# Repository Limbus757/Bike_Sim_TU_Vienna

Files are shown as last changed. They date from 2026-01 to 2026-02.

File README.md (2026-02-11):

# Bike_Sim_TU_Vienna
**Bachelor Thesis Project | TU Wien**

An immersive bicycle simulation environment developed at TU Wien, integrating Unity-based visualization with Arduino hardware for real-time interaction.

Project Overview

---
## Project Structure

| Folder / File | Description |
| :--- | :--- |
| **`Unity Project/`** | The core simulation built in Unity. Includes physics, environments, and UI. |
| **`Arduino Files/`** | Microcontroller firmware for sensor data acquisition and haptic feedback. |
| **`Data Analysis/`** | Scripts and tools for processing simulation logs and performance metrics. |
| **`Documents and 3D Prints/`** | CAD files, datasheets for the elctronics |
---

## Getting Started

### 1. Hardware Setup
* **Microcontroller:** [e.g., Arduino Nano/Uno]
* **Sensors:** [e.g., Potentiometers for steering, Hall effect for speed]
* Upload the code found in `/Arduino Files/` using the Arduino IDE.

### 2. Unity Simulation
* **Version:** [Insert Unity Version, e.g., 2022.3 LTS]
* Open the `Unity Project` folder in Unity Hub.
* Ensure the COM port in the simulation settings matches your Arduino port.

### 3. Data Analysis
* Post-processing scripts are located in `/Data Analysis/`.
* [Optional: Mention if Python or MATLAB is required].

---

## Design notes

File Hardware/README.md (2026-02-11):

# Bike Simulator: Arduino Control System

This repository contains the firmware and hardware documentation for the Bike Simulator project developed at TU Vienna. The system utilizes a dual-microcontroller architecture to bridge the gap between physical hardware (Tacx Trainer, sensors, and motors) and the Unity simulation environment.

---

## Hardware Architecture

The system is split into two primary controllers to ensure real-time performance and safety:

### 1. ESP32-S3: Telemetry Bridge & Sensor Hub
Located in the ESP32-S3_SerialSender folder, this controller acts as the central communication hub.
* **Dual-Core Execution**: Utilizes FreeRTOS to run BLE/Radio management on Core 1 and Serial/PC communication on Core 0 to prevent timing jitter.
* **BLE Connectivity**: Connects to a TACX-II trainer via the Fitness Machine Service (FTMS) using a specific MAC address.
* **Sensor Integration**: Reads analog brake force from front and rear brakes (mapped from 12-bit ADC to a 0-100 scale) and monitors a digital Lane Keep Assist (LKA) toggle.
* **Dynamic Resistance**: Maps total braking force (0-200% sum) to FTMS resistance units (0-1000) and sends it to the trainer.
* **Telemetry Streaming**: Streams 21-byte packed binary packets to the PC at 50Hz (20ms intervals) via Serial.

### 2. Arduino R4 WiFi: Actuator & Haptics Controller
Located in the Arduino-R4-Wifi_SerialReceiver folder, this controller translates Unity commands into physical movement.
* **Steering Control**: Drives a steering motor via a GPT Timer at 20kHz with 12-bit resolution.
* **Haptic Feedback**: Controls DRV2605 haptic drivers via PWM to provide tactile feedback.
* **Safety Watchdog**: Automatically sets motors to a safe state if the Unity application stops responding for more than 75ms.
* **High-Speed Serial**: Operates at a baud rate of 256,000 to ensure low-latency control.

---

## Communication Protocols
Both controllers use a structured binary packet format to ensure efficient data transfer with minimal overhead.

### Telemetry Packet (ESP32 -> PC)
| **Sync Header** | 0xAA 0xBB |
| **Payload** | 21 Bytes: Speed, Front/Rear Brake, Resistance, LKA Switch, Timing |
| **Tail** | 0xCC |

### Control Packet (PC -> Arduino R4)
| **Sync Header** | 0xAA 0xBB |
| **Payload** | 11 Bytes: Motor Enable, Direction, Steering PWM, Haptic PWM |
| **Tail** | 0xCC |

---

### LED Status Indicators (ESP32-S3)
The built-in RGB LED on the ESP32 provides immediate visual feedback on the system state:
* **Red**: Disconnected or initialization failure.
* **Yellow**: Searching for the Tacx Trainer MAC address.
* **Blue**: BLE radio link established (Service Discovery).
* **Purple**: FTMS Handshake in progress (Requesting Control).
* **Green**: Fully Synchronized & Control Active.

---

### Setup & Installation
1.  **Dependencies**:
    * **ESP32**: Requires the NimBLE-Arduino library.
    * **Arduino R4**: Requires Adafruit_DRV2605.h and the included pwm.h.
2.  **Configuration**:
    * In ESP32-S3_SerialSender.ino, verify the TARGET_MAC_ADDR matches your trainer.
3.  **Deployment**:
    * Upload the respective .ino files to their target boards using the Arduino IDE.

## Mechanical & Technical Documentation

In addition to the firmware, this repository includes integrated design and technical files located in the Documents and 3D Prints folder.

### 3D Design Files
* **Format**: All mechanical parts are provided as STEP files, ensuring compatibility with most CAD software (Fusion 360, SolidWorks, etc.).
* **Components**: Includes custom-designed mounts for attaching the sensors, microcontrollers, and the steering motor assembly to the bike frame.

### Technical Datasheets
* **Reference Material**: Includes datasheets for the core electronic components, such as the DRV2605 haptic drivers and motor controllers, to assist with wiring and electrical troubleshooting.

---

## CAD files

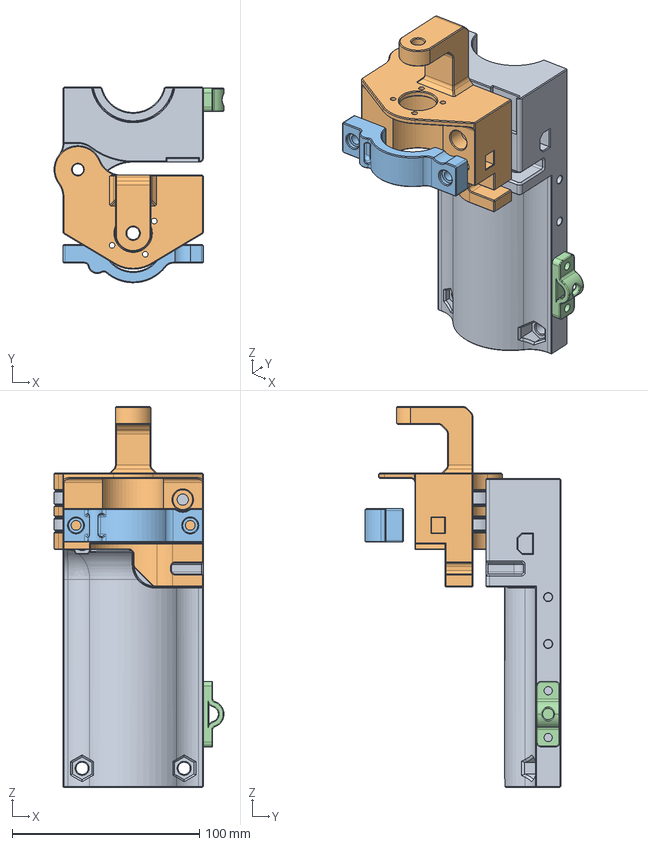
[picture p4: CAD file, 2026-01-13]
Hardware/Datasheets and 3D Prints/3D Print STEP files/Steering_Motor_Clamp_Assembly.step
90.7 x 104.5 x 203.5 mm
Frameclamp_Long
Motor_Mount
FrameClamps_Back
Strain_Relief_Clips

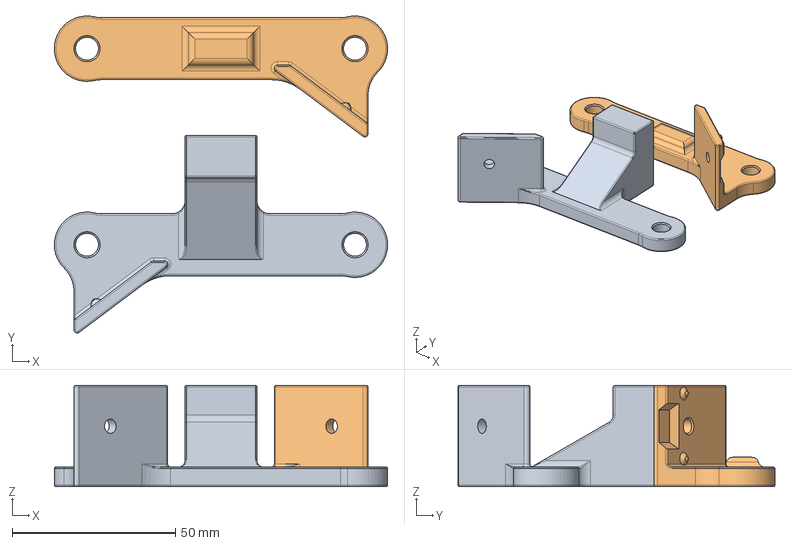
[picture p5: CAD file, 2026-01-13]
Hardware/Datasheets and 3D Prints/3D Print STEP files/Brake_Sensor_Mounts.step
102.0 x 97.0 x 31.0 mm

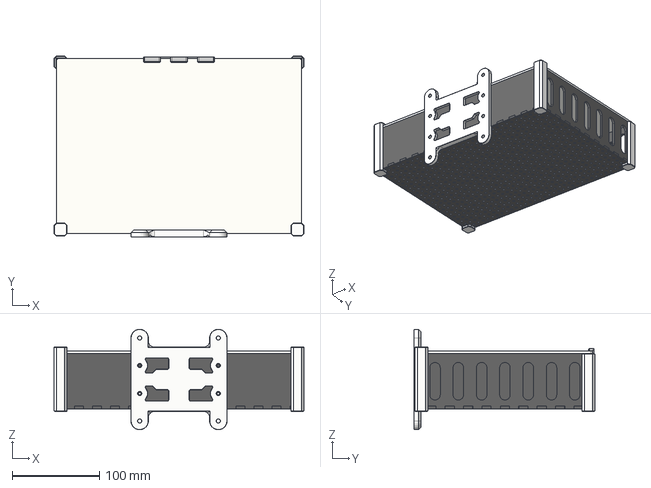
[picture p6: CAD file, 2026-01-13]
Hardware/Datasheets and 3D Prints/3D Print STEP files/Lasercut_Electronic_Enclosure.step
286.0 x 207.0 x 114.9 mm

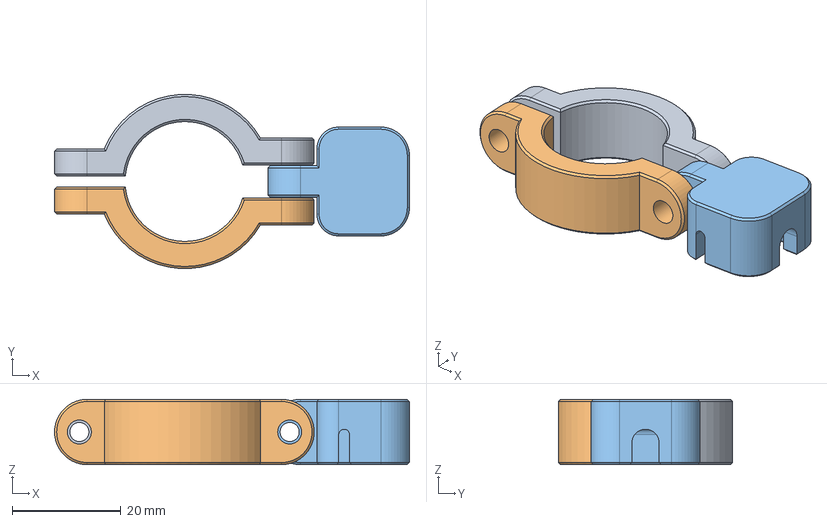
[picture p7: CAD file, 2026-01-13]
Hardware/Datasheets and 3D Prints/3D Print STEP files/Handlebar_Switch_Mount.step
65.2 x 32.0 x 12.0 mm
Handlebar Clamp
Switch Housing

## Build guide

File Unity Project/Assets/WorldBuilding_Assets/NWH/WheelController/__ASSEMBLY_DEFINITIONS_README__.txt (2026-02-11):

This asset uses Assembly Definition (.asmdef) files. There are many benefits to assembly definitions but a downside is that the whole 
project needs to use them or they should not be used at all.

  * If the project already uses assembly definitions accessing a script that belongs to this asset can be done by adding an reference to the assembly 
  definition of the script that needs to reference the asset. E.g. to access WheelController adding a NWH.WheelController reference 
  to [MyProjectAssemblyDefinitionName].asmdef is required.

  * If the project does not use assembly definitions simply remove all the .asmdef files from the asset after import.

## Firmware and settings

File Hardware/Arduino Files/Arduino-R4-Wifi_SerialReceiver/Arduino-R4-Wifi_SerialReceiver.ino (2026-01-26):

/* * FUNCTION:
 * - Receives 11-byte binary packets from Unity.
 * - Drives Steering Motor via GPT Timer (20kHz, 12-bit).
 * - Controls DRV2605 Haptic Drivers via GPT Timer (20kHz, 12-bit).
 * - Watchdog safety stops motors if Unity stops responding for > 75ms.
 */

#include <Wire.h>
#include <Adafruit_DRV2605.h>
#include "pwm.h" // Standard R4 Renesas Core PWM library

// --- CONFIGURATION ---
#define SERIAL_BAUDRATE 256000
#define TIMEOUT_THRESHOLD_MS 75 

// --- PIN DEFINITIONS ---
const int SM_ENABLE_PIN = 10;    
const int SM_DIRECTION_PIN = 9;  
const int SM_PWM_PIN = 8;        

const int VM_EN_L_PIN = 6;       
const int VM_EN_R_PIN = 7;      
const int VM_PWM_L_PIN = 5;      
const int VM_PWM_R_PIN = 3;     

// --- 12-BIT PWM CONSTANTS (0-4095) ---
const uint16_t SM_MIN_LIMIT = 410;   // 10% floor for ESCON
const uint16_t SM_MAX_LIMIT = 3685;  // 90% ceiling
const uint16_t VM_IDLE_PWM  = 2048;  // Neutral haptic value

// --- BINARY PACKET STRUCTURE ---
// Matches Unity [StructLayout(LayoutKind.Sequential, Pack = 1)]
struct __attribute__((packed)) ControlData {
    uint8_t  smEnable;       
    uint8_t  smDirection;    
    uint16_t smPwm;         
    uint16_t vmLeftPwm;     
    uint16_t vmRightPwm;    
};

ControlData currentData = {0, 0, SM_MIN_LIMIT, VM_IDLE_PWM, VM_IDLE_PWM}; 
unsigned long lastDataTime = 0;
bool firstData = false;

Adafruit_DRV2605 drv;

// Configure DRV2605 Drivers
bool configVMDriver(int enPin) {
    digitalWrite(VM_EN_L_PIN, LOW);
    digitalWrite(VM_EN_R_PIN, LOW);
    delay(10);
    digitalWrite(enPin, HIGH); 
    delay(20);
    if (!drv.begin()) return false;
    drv.setMode(DRV2605_MODE_PWMANALOG); 
    return true;
}

void setFrequencies() {
    
    uint32_t period_us = 1000; 

    PwmOut smPwm(SM_PWM_PIN);
    smPwm.begin(period_us, 0, false, TIMER_SOURCE_DIV_1); 

    PwmOut vmL(VM_PWM_L_PIN);
    vmL.begin(period_us, 0, false, TIMER_SOURCE_DIV_1);

    PwmOut vmR(VM_PWM_R_PIN);
    vmR.begin(period_us, 0, false, TIMER_SOURCE_DIV_1);
}

void applySignals() {
    digitalWrite(SM_ENABLE_PIN, currentData.smEnable ? HIGH : LOW);
    digitalWrite(SM_DIRECTION_PIN, currentData.smDirection ? HIGH : LOW);
    
    // Apply Steering with safety clamp
    uint16_t clampedSM = constrain(currentData.smPwm, SM_MIN_LIMIT, SM_MAX_LIMIT); 
    analogWrite(SM_PWM_PIN, clampedSM); 
  
    // Apply Haptics
    analogWrite(VM_PWM_L_PIN, currentData.vmLeftPwm);
    analogWrite(VM_PWM_R_PIN, currentData.vmRightPwm);
}

void setSafeState() {
    currentData.smEnable = 0;
    currentData.smDirection = 0;
    currentData.smPwm = SM_MIN_LIMIT;
    currentData.vmLeftPwm = VM_IDLE_PWM; 
    currentData.vmRightPwm = VM_IDLE_PWM; 
    applySignals();
}

void setup() {
    Serial.begin(SERIAL_BAUDRATE);
    Wire.begin();

    // Set 12-bit resolution for all analogWrite calls
    analogWriteResolution(12);

    pinMode(SM_ENABLE_PIN, OUTPUT);
    pinMode(SM_DIRECTION_PIN, OUTPUT);
    pinMode(SM_PWM_PIN, OUTPUT);
    pinMode(VM_EN_L_PIN, OUTPUT);
    pinMode(VM_EN_R_PIN, OUTPUT);
    pinMode(VM_PWM_L_PIN, OUTPUT);
    pinMode(VM_PWM_R_PIN, OUTPUT);

    setFrequencies(); 
    setSafeState();

    if (!configVMDriver(VM_EN_L_PIN)) Serial.println("VM_L Fail");
    if (!configVMDriver(VM_EN_R_PIN)) Serial.println("VM_R Fail");
    
    digitalWrite(VM_EN_L_PIN, HIGH);
    digitalWrite(VM_EN_R_PIN, HIGH);
}

void loop() {
    while (Serial.available() >= 11) {
        // 2. Look for the start of the packet (0xAA 0xBB)
        if (Serial.read() == 0xAA) {
            if (Serial.peek() == 0xBB) { // Peek to confirm second header byte
                Serial.read(); // Consume the 0xBB

                // 3. Fast-read the payload directly into the struct memory
                byte* p = (byte*)&currentData;
                for (size_t i = 0; i < sizeof(ControlData); i++) {
                    p[i] = Serial.read();
                }


                if (Serial.read() == 0xCC) {
                    firstData = true;
                    lastDataTime = millis();
                    
                    applySignals();
                }
            }
        }
    }

    // --- Safety Watchdog ---
    if (firstData && (millis() - lastDataTime > TIMEOUT_THRESHOLD_MS)) {
        setSafeState(); 
    }
}

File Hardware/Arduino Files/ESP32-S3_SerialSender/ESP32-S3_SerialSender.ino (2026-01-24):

/*
 ESP32-S3 Trainer Controller: BLE Central & Telemetry Bridge
 =========================================================================
  Core Architecture:
  - Dual-Core Execution: BLE/Radio on Core 1, Serial/PC Link on Core 0.
  - Thread Safety: Mutex-protected shared sensor and speed variables.
  - Memory: Optimized stack usage with static telemetry allocation.

  Logic flow:
  1. Sensors: Reads analog brake force (0-4095) and digital LKA toggle.
  2. BLE: Connects to TACX via MAC; initializes FTMS Control Point (0x2AD9).
  3. Control: Maps 0-200% brake sum to 0-1000 resistance units (OpCode 0x04).
  4. Telemetry: Streams 21-byte packed binary packets to PC at 50Hz.

  Serial Packet Structure:
  [0xAA][0xBB] + [21 Bytes Telemetry] + [0xCC]

  LED Status:
  - RED: Disconnected / Initializing
  - YELLOW: Searching for TACX MAC Address
  - BLUE: BLE Radio Link established (Service Discovery)
  - PURPLE: FTMS Handshake in progress (Requesting Control)
  - GREEN: Fully Synchronized & Control Active
 */


#include <Arduino.h>
#include <NimBLEDevice.h>

// === configuration ===
#define SERIAL_BAUDRATE         115200
#define BLE_TIMING_INTERVAL_MS  20      
#define PC_SEND_INTERVAL_MS     20      

// === TACX-II connection settings ===
const char* TARGET_MAC_ADDR = "d3:42:b3:d4:26:1A";
// 0 = Public, 1 = Random. This Trainer uses random for some reason.
uint8_t BLE_ADDR_TYPE = 1; 

// === esp32 sensor pins ===
#define FRONTBRAKE_PIN 1
#define REARBRAKE_PIN  2
#define LKA_SWITCH_PIN 5

// === led control ===
#define RGB_BUILTIN     48
#define RGB_BRIGHTNESS  255

// Data packet for PC communication (Packed to ensure no padding bytes)
struct __attribute__((packed)) TelemetryData {
    float speed;          
    float frontBrake;     
    float rearBrake;      
    uint16_t resistance;  
    uint8_t lkaSwitch;    
    uint32_t blePeriod;   
    uint32_t serialPeriod;
};

// === ble globals ===
const char* FTMS_SERVICE_UUID = "1826";           // Fitness Machine Service
const char* INDOOR_BIKE_DATA_CHAR_UUID = "2ad2";  // Speed/Power data
const char* CONTROL_POINT_CHAR_UUID  = "2ad9";    // Resistance control

static NimBLEClient* pClient = nullptr;
static NimBLERemoteCharacteristic* pIndoorBikeDataChar = nullptr;
static NimBLERemoteCharacteristic* pControlPointChar = nullptr;
volatile bool bleConnected = false;
volatile bool fCPinit = false;

// Shared data protected by Mutex
SemaphoreHandle_t xSensorMutex;
volatile float speedf = 0.0; 
volatile float frontBrakeForce = 0.0; 
volatile float rearBrakeForce  = 0.0; 
volatile bool  lkaSwitchState  = false; 
volatile uint16_t resistanceValue = 0; 
volatile uint32_t bleActualPeriodMs    = 0; 

// === sensor logic ===
void readSensors(float &frontBrake, float &rearBrake, bool &switchState) {
    // Convert 12-bit ADC (0-4095) to 0-100% scale
    frontBrake = map(analogRead(FRONTBRAKE_PIN), 0, 4095, 0, 100);
    rearBrake  = map(analogRead(REARBRAKE_PIN), 0, 4095, 0, 100);
    switchState = (digitalRead(LKA_SWITCH_PIN) == HIGH); 
}

uint16_t calculateResistance(float frontBrake, float rearBrake) {
    float totalBrake = frontBrake + rearBrake;
    // Map total brake force to FTMS resistance range (0-1000)
    return map(totalBrake, 0.0, 200.0, 0, 1000);
}

// === ble connection logic ===
void writeResistanceToTacx(uint16_t resistance) {
    if (!bleConnected || !fCPinit || !pControlPointChar) return;
    // Opcode 0x04 = Set Target Resistance, followed by uint16 little-endian
    uint8_t payload[3] = { 0x04, (uint8_t)(resistance & 0xFF), (uint8_t)((resistance >> 8) & 0xFF) };
    pControlPointChar->writeValue(payload, 3, false);
}

void initFitnessMachineControlPoint() {
    if (!pControlPointChar || fCPinit) return;
    rgbLedWrite(RGB_BUILTIN, RGB_BRIGHTNESS, 0, RGB_BRIGHTNESS); // Purple: Handshaking
    
    // Request Control
    uint8_t requestControl[] = {0x00};
    if (pControlPointChar->writeValue(requestControl, 1, true)) {
        vTaskDelay(pdMS_TO_TICKS(200)); 
    }

    // Start/Reset the trainer
    uint8_t startCmd[] = {0x07};
    if (pControlPointChar->writeValue(startCmd, 1, true)) {
        vTaskDelay(pdMS_TO_TICKS(200));
        writeResistanceToTacx(0);
        fCPinit = true;
        rgbLedWrite(RGB_BUILTIN, 0, RGB_BRIGHTNESS, 0); // Green: Fully Ready
    }
}

// Callback for incoming trainer data (speed)
static void notifyCallback(NimBLERemoteCharacteristic* pChar, uint8_t* pData, size_t len, bool isNotify) {
    if (len > 3) {
        // FTMS Speed is in 0.01 km/h increments
        uint16_t rawSpeed = (uint16_t)pData[2] | ((uint16_t)pData[3] << 8);
        if (xSemaphoreTake(xSensorMutex, portMAX_DELAY) == pdTRUE) {
            speedf = rawSpeed * 0.01f;
            xSemaphoreGive(xSensorMutex);
        }
    }
}

class ClientCallbacks : public NimBLEClientCallbacks {
    void onConnect(NimBLEClient* p) override { bleConnected = true; }
    void onDisconnect(NimBLEClient* p, int reason) override { 
        bleConnected = false; 
        fCPinit = false;
        pIndoorBikeDataChar = nullptr; // Clear characteristic pointers
        pControlPointChar = nullptr;   
        
        NimBLEDevice::deleteClient(p); // Wipe memory and free RAM
        pClient = nullptr;             // Reset global client pointer
        
        rgbLedWrite(RGB_BUILTIN, RGB_BRIGHTNESS, 0, 0); // Red: Disconnected
    }
};

void connectToTacx() {
    // Define address using user-specified type (Public/Random)
    NimBLEAddress targetAddr(TARGET_MAC_ADDR, BLE_ADDR_TYPE);
    
    rgbLedWrite(RGB_BUILTIN, RGB_BRIGHTNESS, 100, 0); // Yellow: Searching

    pClient = NimBLEDevice::createClient();
    pClient->setClientCallbacks(new ClientCallbacks());

    // Direct connection via MAC address (skips scanning)
    if (pClient->connect(targetAddr)) {
        rgbLedWrite(RGB_BUILTIN, 0, 0, RGB_BRIGHTNESS); // Blue: Radio linked
        
        NimBLERemoteService* pSvc = pClient->getService(FTMS_SERVICE_UUID);
        if (pSvc) {
            pIndoorBikeDataChar = pSvc->getCharacteristic(INDOOR_BIKE_DATA_CHAR_UUID);
            pControlPointChar = pSvc->getCharacteristic(CONTROL_POINT_CHAR_UUID);
            
            if (pIndoorBikeDataChar && pControlPointChar) {
                pIndoorBikeDataChar->subscribe(true, notifyCallback);
                initFitnessMachineControlPoint(); 
                return;
            }
        }
        pClient->disconnect();
    }
    
    // Clean up if connection or service discovery fails
    NimBLEDevice::deleteClient(pClient);
    pClient = nullptr;
    rgbLedWrite(RGB_BUILTIN, RGB_BRIGHTNESS, 0, 0);
}
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

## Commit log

2025-07-30 add new steering input classes
2025-08-20 remove steering scripts
2025-08-20 add documentation folder and class diagram, rename arduino folder
2025-08-20 refactor of bike and arduino logic
2025-08-21 remove libraries
    [Cone.obj, Oculus_IAP.tsv]
2025-08-24 add utility folder for bikescripts and wheel rotation
2025-08-24 attach script files to wheels
2025-08-26 implement first draft of LKA & rename wheelturning script
2025-08-27 add serial tests with arduino files
2025-10-01 rework of arduino script, fixing some issues with Serial
2025-10-14 add esp32s3 sketch
2025-10-22 arduino code haptic feedback
2025-10-29 Fixed VR Problems, Added XR Camera Rig Added Distance Measurement for Splines
2025-11-25 Brakevalues changed
2025-12-17 create testing script for motor PWM and update ESP32 comments
2025-12-21 add first receive script draft for arduino r4
2026-01-01 update logging framework and add trigger object
2026-01-01 update lanekeeping script with new logic and curvature detection on track
2026-01-08 fix ESP32 connection issues and reorganize folder
    [haptic_feedback.ino]
2026-01-10 fix ESP32 resistance Issue
2026-01-10 add various fixes and steering calibration
2026-01-12 change pins for steering PWM
2026-01-12 Add STEP files for 3D models used in the sim
    [Brake_Sensor_Mounts.step, Handlebar_Switch_Mount.step, Lasercut_Electronic_Enclosure.step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]
2026-01-14 adjust vib motor PWM range
2026-01-19 fix some steering issues and add further code cleanup
2026-01-19 new Track
2026-01-21 improve arduino r4 serial parsing
2026-01-21 update LKA PID variables
2026-01-23 add multiple updates to track texture and track alignment
2026-01-24 Update study parameters and add improvements to LKAConfig regarding PWM ranges
    Changed study participant ID, condition, total rounds, end study text, and current lap in BikeSimulator.unity. Added a new mesh object to the scene. Modified several scripts related to lane keeping a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
2026-01-24 improve ESP32S3 Connection to TACX and add improved data packet sending for Arduino R4 and ESP32
2026-01-25 add new track designs to Unity scene
2026-01-26 change track and align trees and buildings
2026-01-27 fix logging issue and track width
2026-02-05 add raw data and update script
    [10_BaselineCC_20260128_180051.csv, 10_BaselineCW_20260128_173052.csv, 10_HapticsAdaptiveCC_20260128_174548.csv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]
2026-02-05 update csvs
    [10_BaselineCC_20260128_180051.csv, 10_BaselineCW_20260128_173052.csv, 10_HapticsAdaptiveCC_20260128_174548.csv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]
2026-02-08 Paricipant 5 secondary task
    [5_BaselineCC_20260128_105450.csv, 5_BaselineCW_20260128_102849.csv, 5_HapticsAdaptiveCC_20260128_110507.csv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]
2026-02-08 Secondary Task Statistics
    [secondary_task_summary.csv]
2026-02-08 add analysis of secondary task into boxplots
    [5_BaselineCC_20260128_105450.csv, 5_BaselineCW_20260128_102849.csv, 5_HapticsAdaptiveCC_20260128_110507.csv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]
2026-02-10 update boxplot script
    [5_BaselineCC_20260128_105450.csv, 5_BaselineCW_20260128_102849.csv, 5_HapticsAdaptiveCC_20260128_110507.csv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]
2026-02-11 reorganize folder structure
    [10_BaselineCC_20260128_180051.csv, 10_BaselineCW_20260128_173052.csv, 10_HapticsAdaptiveCC_20260128_174548.csv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]
2026-02-11 readd raw data
    [10_BaselineCC_20260128_180051.csv, 10_BaselineCW_20260128_173052.csv, 10_HapticsAdaptiveCC_20260128_174548.csv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]
2026-02-11 add further organization and documentation to hardware
    [Brake_Sensor_Mounts.step, Handlebar_Switch_Mount.step, Lasercut_Electronic_Enclosure.step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]
2026-02-13 update data analysis pipeline
    [12_HapticsAdaptiveCC_20260129_113016.csv, 12_HapticsAdaptiveCW_20260129_113016.csv, 5_BaselineCC_20260128_105450.csv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]
2026-02-22 update data processing pipeline
    [10_BaselineCC_20260128_180051.csv, 10_BaselineCW_20260128_173052.csv, 10_HapticsAdaptiveCC_20260128_174548.csv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]
2026-02-23 update data processing
    [fully_combined_metrics_aggregated.csv, merged_trial_level_metrics.csv]
2026-09-22 chore: delete unneccessary directories
    [10_BaselineCC_20260128_180051.csv, 10_BaselineCW_20260128_173052.csv, 10_HapticsAdaptiveCC_20260128_174548.csv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]
